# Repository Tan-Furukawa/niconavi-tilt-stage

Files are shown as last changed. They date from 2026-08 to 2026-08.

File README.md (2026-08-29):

# niconavi-tilt-stage


A thin-section (microscope slide) holder and tilt stage for the NicoNavi software. It is built from four 3D-printed parts plus M2 screws and nuts.

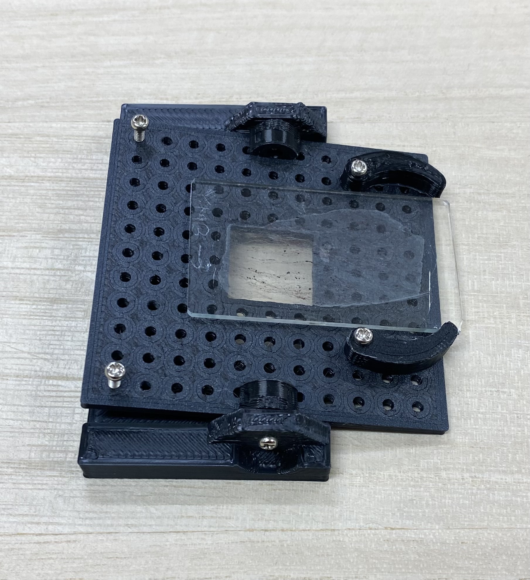
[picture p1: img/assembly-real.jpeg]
Assembled


---

## 1. Parts

### 3D-printed parts (STL)

| File | Name | Qty |
| --- | --- | --- |
| [frame.stl](frame.stl) | Frame (U-shaped base) | 1 |
| [plate.stl](plate.stl) | Main plate (perforated plate) | 1 |
| [bearing.stl](bearing.stl) | Bearing (knob / tilt axis) | 2 |
| [clip.stl](clip.stl) | Clip (sample retainer) | 2 |

### Parts to prepare separately

| Item | Qty |
| --- | --- |
| M2 × 8 mm pan-head screw | 6 |
| M2 nut | 2 |
| Double-sided tape | a little |
| Circular bubble level | optional |

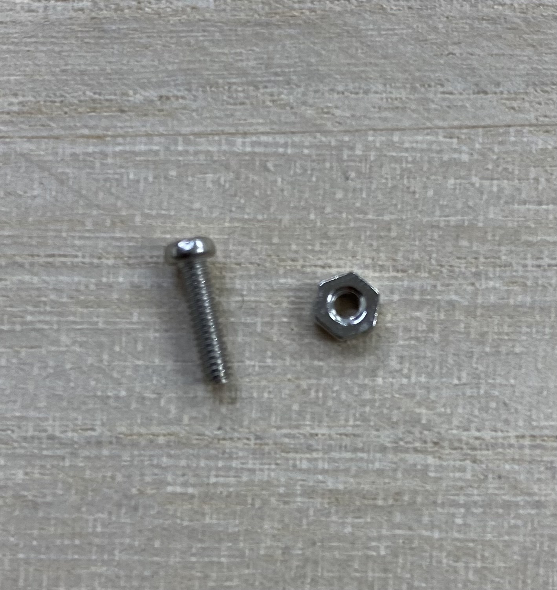
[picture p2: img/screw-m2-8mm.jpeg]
M2 screw and nut


### Tools

- Phillips screwdriver
- Vise or pliers (for pressing in the nuts)

---

## 2. Assembly

The overall arrangement is shown below.

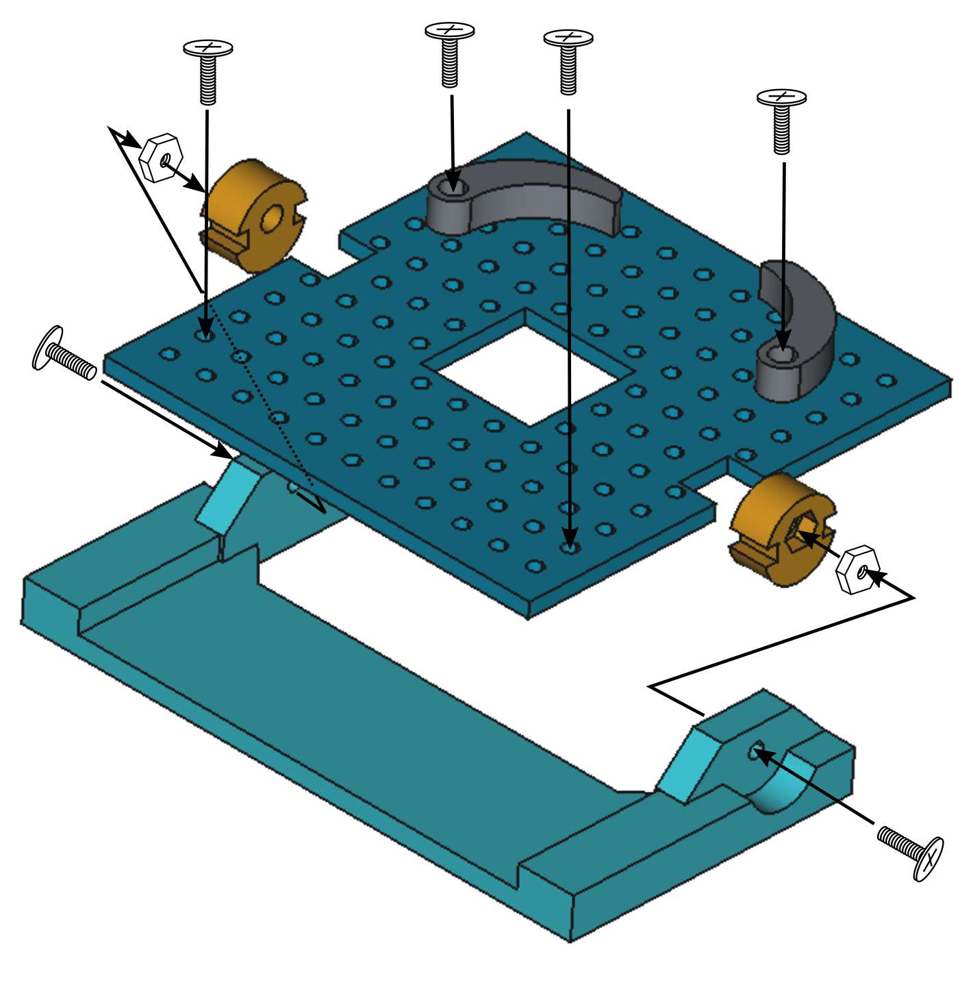
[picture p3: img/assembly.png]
Exploded view


### Step 1. Press an M2 nut into the bearing

Push an M2 nut into the hexagonal pocket of the bearing (`bearing.stl`).

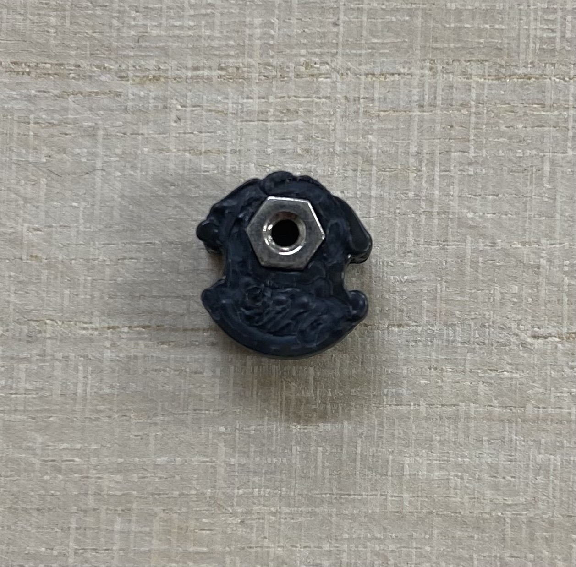
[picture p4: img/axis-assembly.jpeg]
Pressing the nut into the bearing


- If it will not go in by hand, **press it in with a vise or pliers**.
  The trick is to push evenly with a flat surface.
- **You may also tap it in.** Put the part on a flat surface, place a hard
  block on top of the nut, and tap it in lightly.

Make two of these.

### Step 2. Attach the bearings to the main plate

Fit the two bearings from Step 1 into the notches on the left and right of the
main plate (`plate.stl`) and fix them from above with M2 × 8 mm screws
(**2 screws**).

- **The bearing has an up/down orientation.** The side the nut went into faces
  up — that is, mount it so that **the nut (i.e. the tilt axis) sits slightly
  above the surface of the main plate**. If it is upside down, the axis height
  will not line up.
- The nut faces outward.

### Step 3. Attach the clips

On the top face of the main plate, fix two clips (`clip.stl`) with
M2 × 8 mm screws so that they sit on either side of the square opening
(the viewing window) in the center (**2 screws**).

- **The clips are optional.** Depending on where the thin section sits, it may
  stay put without them. Attach them when the section tends to slide around.
- Tighten the screws **loosely enough that the clips can still rotate**.
  The clips hold the sample by being turned, so do not tighten them fully.
- Point the curved tip of each clip toward the center of the viewing window.

### Step 4. Set the plate on the frame and insert the axis screws

Drop the main plate between the arms of the U-shaped frame (`frame.stl`),
then insert M2 × 8 mm screws through the holes on the outside of the arms and
thread them into the nuts pressed in at Step 1 (**2 screws**).

- How tight they are determines how well the tilt angle holds.
  - Too tight → the plate will not move
  - Too loose → the plate droops during observation

  The sweet spot is when **the plate moves when you push it and stays at that
  angle when you let go**.

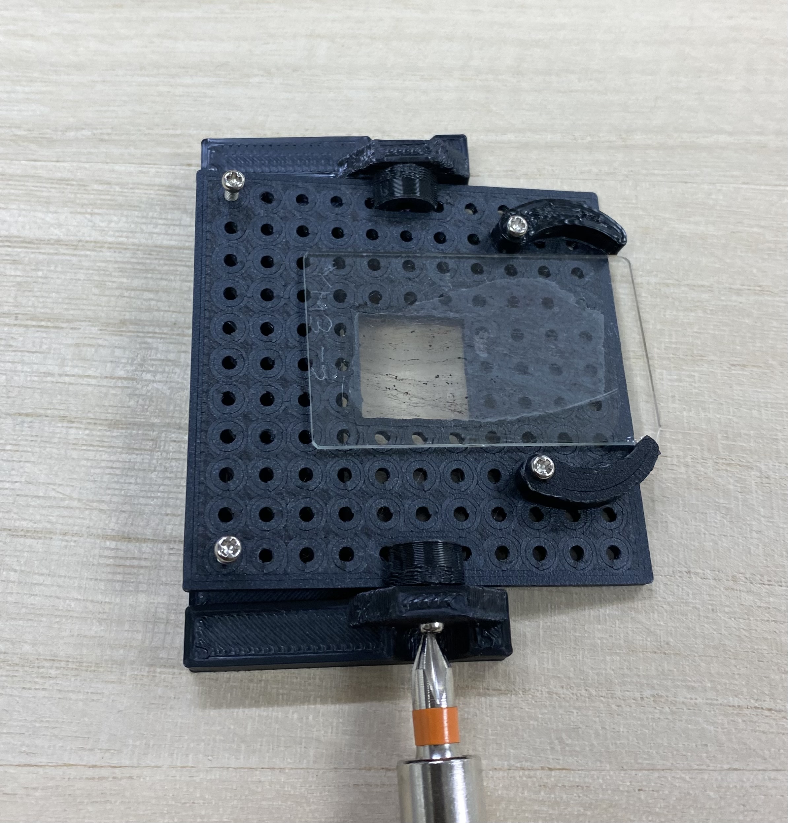
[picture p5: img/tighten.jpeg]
Tightening the axis screw


### Step 5. Mount on the microscope stage

Apply double-sided tape to the flat bottom face of the frame and stick it onto
the microscope stage.

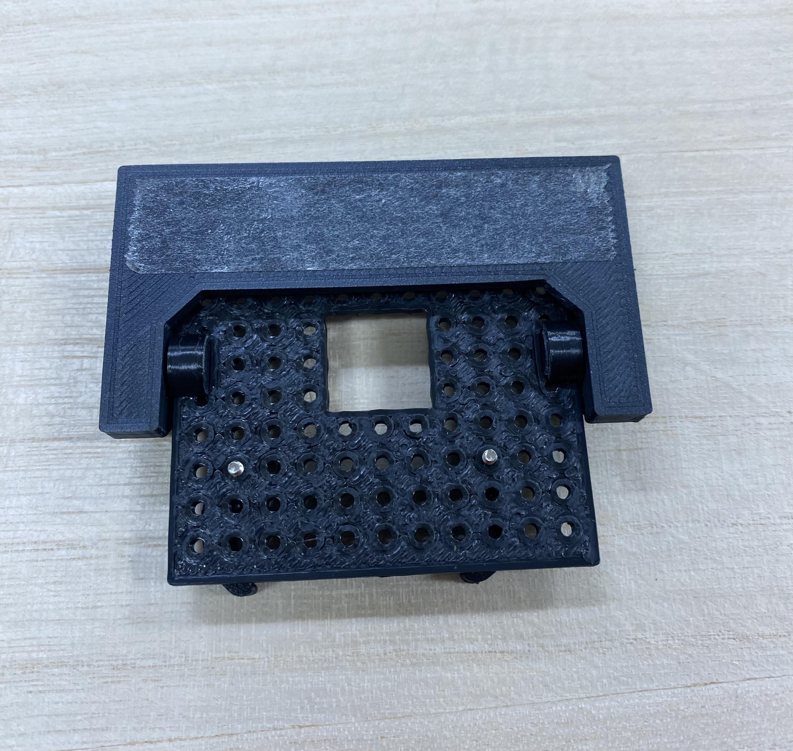
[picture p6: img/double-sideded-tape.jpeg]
Double-sided tape


- Line the viewing window (the square opening) up with the optical path of the
  objective lens before sticking it down.

---

## 3. Usage

### Setting a thin section

1. Place the thin section (slide) over the viewing window and bring the area
   you want to observe to the center of the window.
2. If the section slides around, turn the clips inward to hold its edges lightly.

Thin section in place

### Leveling

Place a circular bubble level on the main plate and adjust until the bubble is
centered.

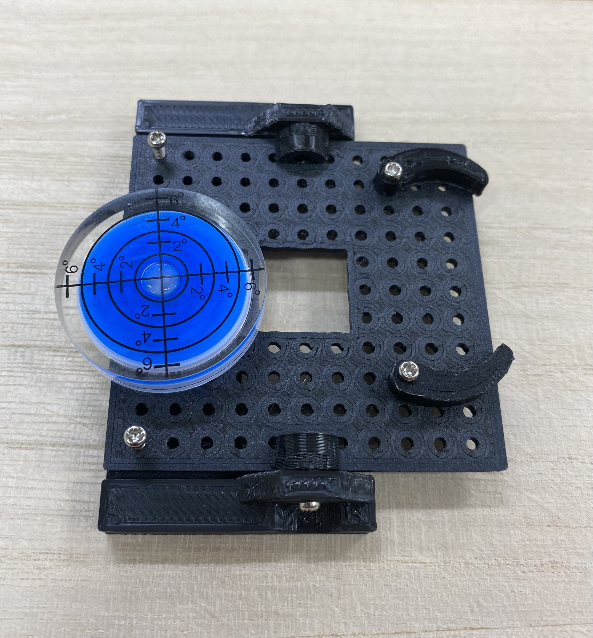
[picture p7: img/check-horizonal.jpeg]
Checking level


- Adjust with the **two screws on the left side of the photo**, tightening or
  loosening them a little at a time.

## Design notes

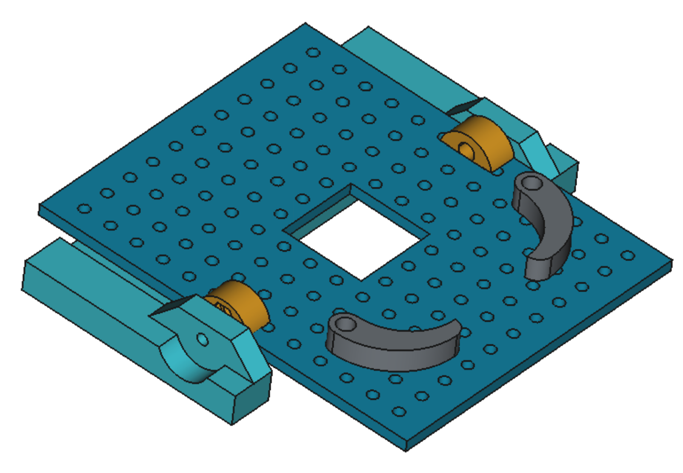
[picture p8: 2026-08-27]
img/tilt-stage.png

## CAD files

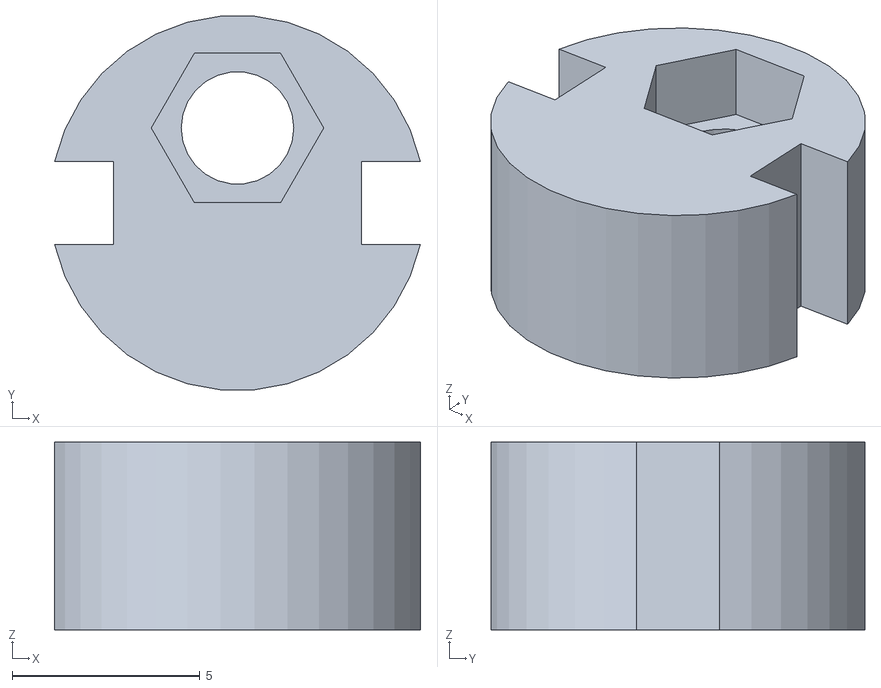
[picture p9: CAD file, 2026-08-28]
bearing.stl
9.75 x 9.96 x 5.00

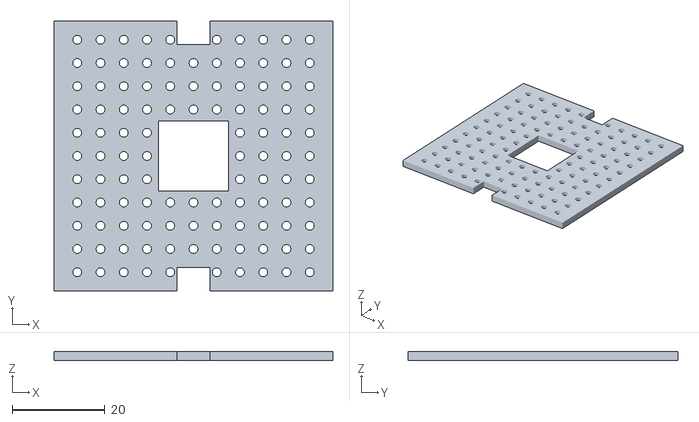
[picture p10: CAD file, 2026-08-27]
plate.stl
60.0 x 58.0 x 2.00

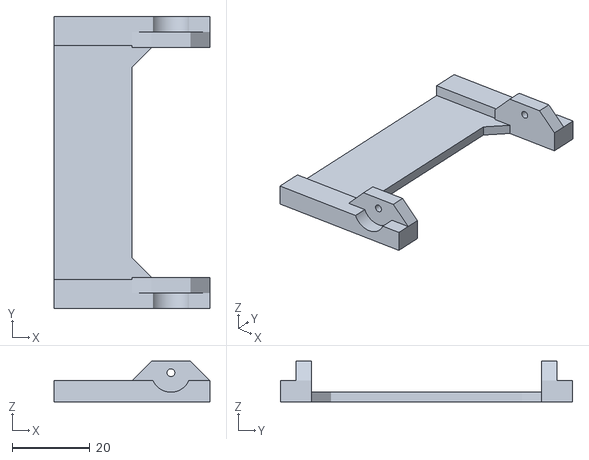
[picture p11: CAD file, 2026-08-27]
frame.stl
40.0 x 75.0 x 10.5

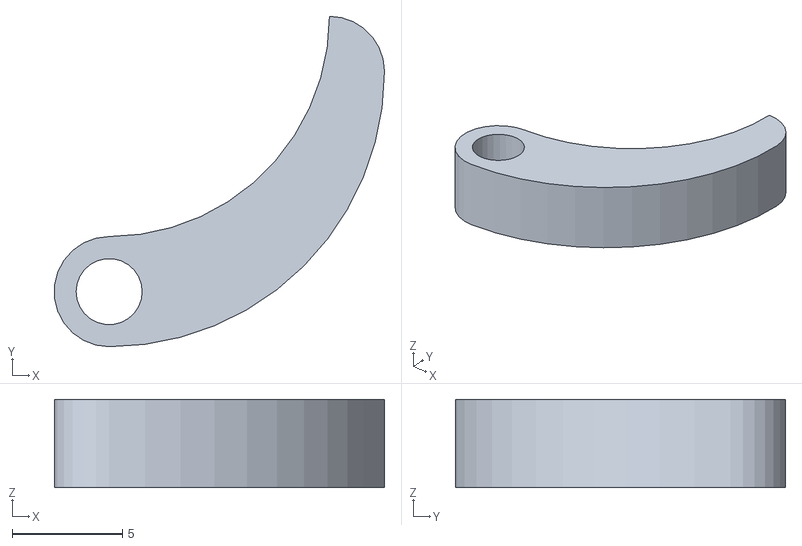
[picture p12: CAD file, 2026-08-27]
clip.stl
15.0 x 15.0 x 4.00

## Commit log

2026-08-28 Add assembly instructions to README
    Document how to assemble the tilt stage: parts list, nut press-fit into the
    bearings, mounting the bearings and clips on the main plate, the tilt axis
    screws, sticking the frame to the microscope stage, and leveling.
    Also add the photos referenced by the instructions, update bearing.stl, and
    ignore the FreeCAD source file.
    [bearing.stl]
2026-08-28 Rename project to niconavi-tilt-stage in README
